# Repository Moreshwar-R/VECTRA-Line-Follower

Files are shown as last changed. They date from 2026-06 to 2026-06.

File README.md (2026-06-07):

# 🏁 VECTRA — Line Follower Robot

**ESP32 · TB6612FNG · 10-channel IR array · LSRB intersection logic + Anti-Wobble PID**

VECTRA is a high-speed competition line follower designed to stay locked on the track even when the layout changes from one event to the next. A wide 10-channel IR array reads sharp turns, acute angles and intersections, while decisive LSRB logic layered over a tuned PID controller keeps every junction predictable. Built around an ESP32 and a TB6612FNG driver, it balances speed, stability and fast trackside tuning.

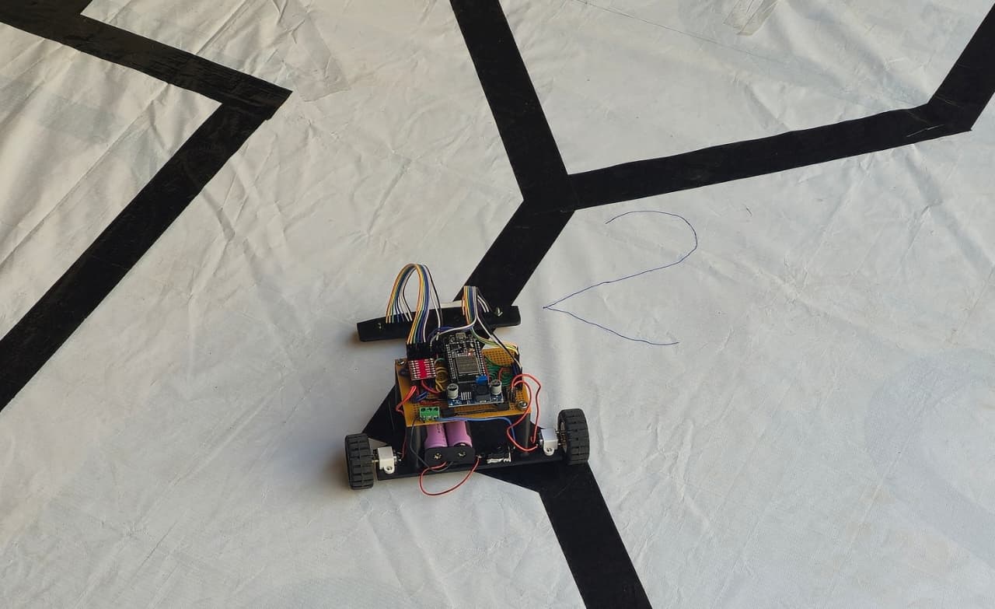
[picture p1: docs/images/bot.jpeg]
VECTRA line follower robot


<br>

VECTRA run demo

</div>

---

## ✨ Features

- **Wide 10-sensor coverage** — handles different track layouts without re-wiring.
- **LSRB intersection logic** — Left > Straight > Right priority at junctions.
- **Anti-wobble PID** — dead-band stops shivering on straights, saving time.
- **Line-lost recovery** — remembers last turn direction and sweeps back to the line.
- **Efficient drive** — TB6612FNG H-bridge with N20 micro-gear motors.

---

## 🧩 Components

| Component | Qty | Description |
|---|:---:|---|
| ESP32 DevKit (30-pin) | 1 | Dual-core microcontroller — reads the sensors and runs the control loop. |
| TB6612FNG motor driver | 1 | Dual H-bridge that drives both motors efficiently and cool. |
| N20 6V micro-gear motor + wheel | 2 | Provides drive; compact and quick. |
| Front caster wheel | 1 | Third contact point for smooth balance. |
| 10-channel reflective IR array | 1 | Senses the line; wide span covers changing track maps. |
| LM2596 buck module | 1 | Steps the 7.4 V battery down to a clean 5 V for the logic. |
| 2S Li-ion battery (7.4 V) | 1 | Main power source. |
| SPST switch | 1 | Master power cut-off. |
| Chassis, standoffs, wires, connectors | — | Frame and interconnections. |

---

## ⚙️ How It Works

1. **Read** the IR array and compute a weighted line `error` (outer sensors pull harder).
2. **Intersections / acute turns (LSRB):** left has priority, straight beats right, sharp turns snap.
3. **Line lost:** spin toward the last known turn until the line is reacquired.
4. **PID steering:** `correction = Kp·error + Kd·(error − lastError)`, applied differentially.

---

## 🛠️ Hardware Design

**Schematic**

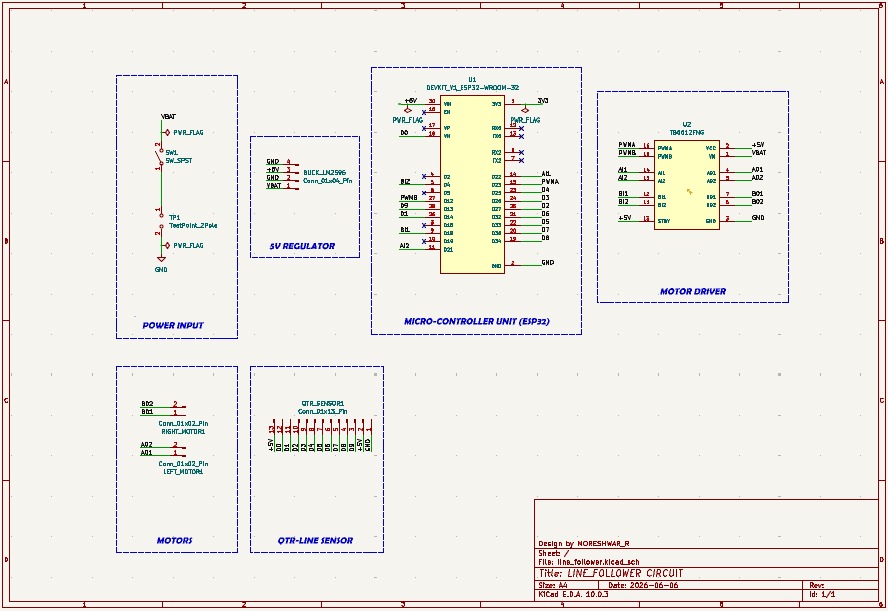
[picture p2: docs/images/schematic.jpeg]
Schematic


<br>

**PCB Layout**

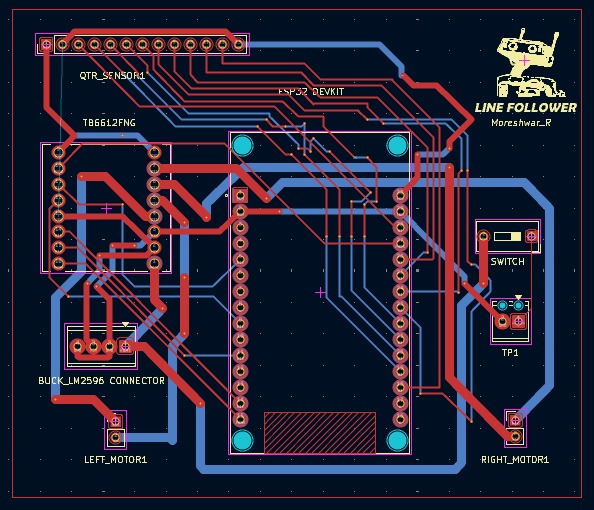
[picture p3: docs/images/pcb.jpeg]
PCB layout


<br>

**3D Model**

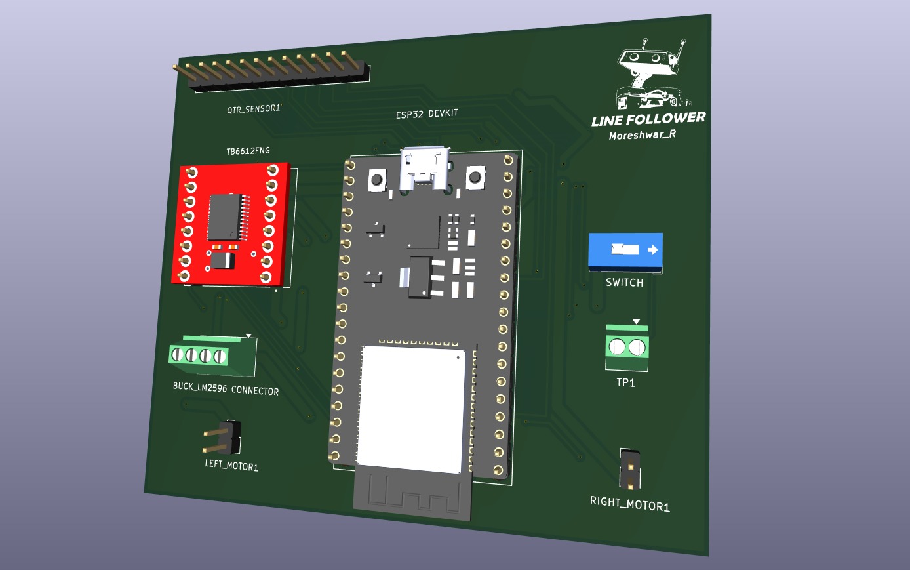
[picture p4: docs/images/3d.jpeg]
3D model


</div>

---

## 💾 Firmware & Tuning

- Sketch → [`firmware/line_follower.ino`](firmware/line_follower.ino)
- Board: **ESP32 Dev Module** · Library: **QTRSensors**

| Variable | Default | Role |
|---|:---:|---|
| `Kp` | 15 | Correction strength |
| `Kd` | 30000 | Damping / overshoot control |
| `baseSpeed` | 250 | Cruise speed (0–255) |
| `THRESHOLD` | 4090 | Black/white cutoff (recalibrate per track) |

---

## 📜 License

- Released under the **MIT License** — see [`LICENSE`](LICENSE).
- Free to use, fork and race.

---

## 🏷️ Topics

`#LineFollower` `#ESP32` `#TB6612FNG` `#PID` `#LSRB` `#Robotics` `#Arduino` `#Embedded` `#KiCad`

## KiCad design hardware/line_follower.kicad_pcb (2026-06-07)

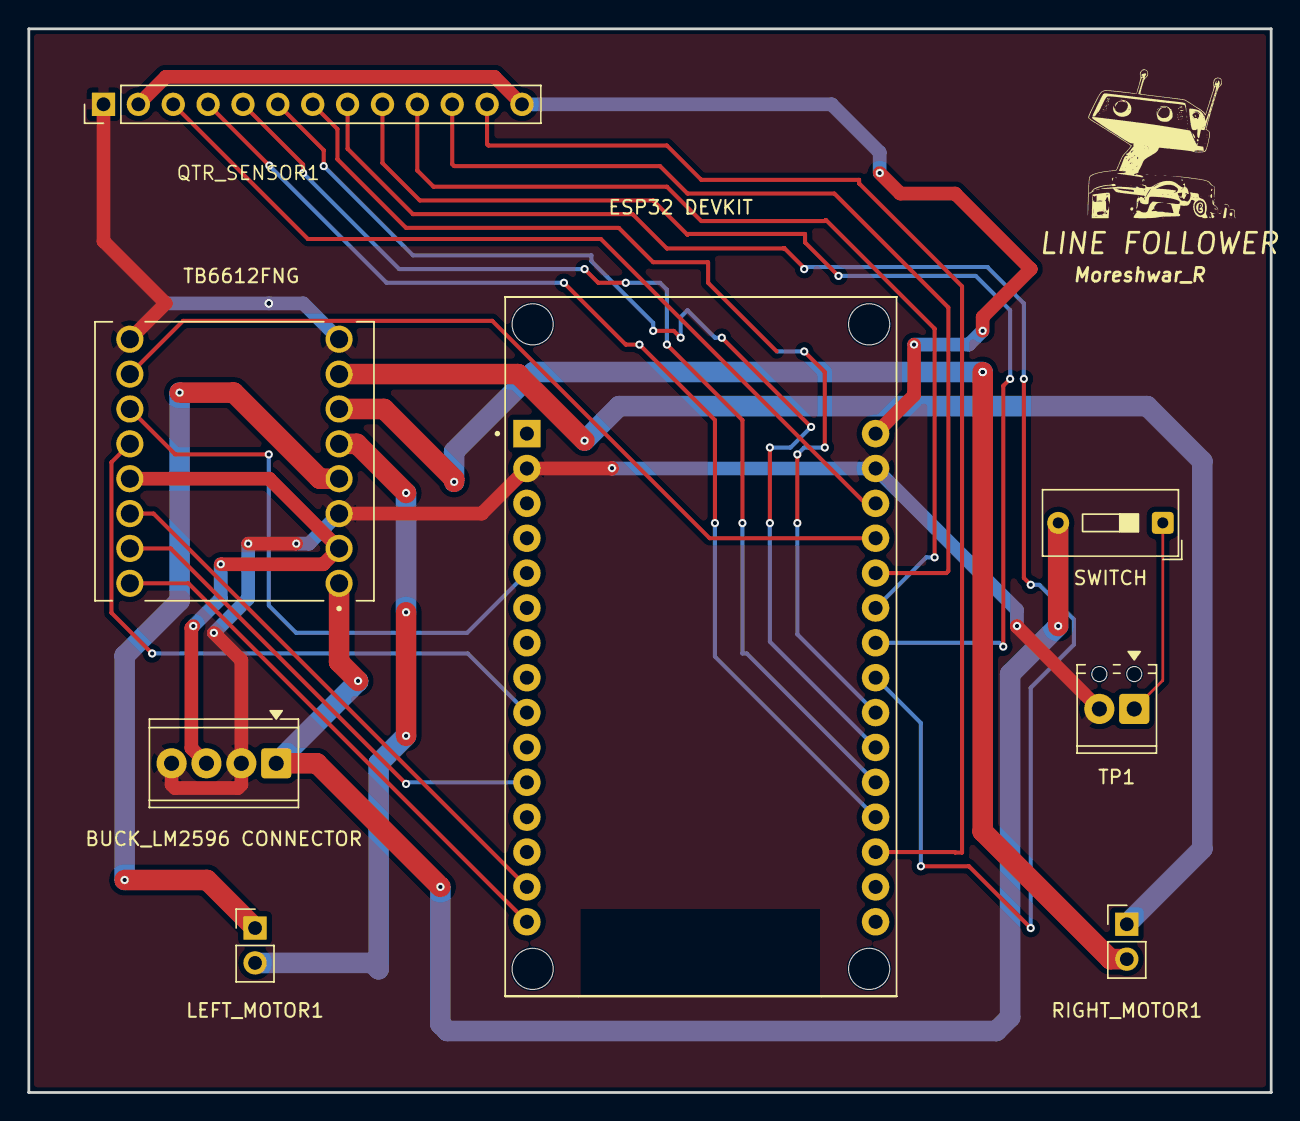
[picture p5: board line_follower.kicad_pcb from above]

Board: 2 copper layers, 90.5 x 77.5 mm, 8 parts (0 on the bottom side), 24 nets.

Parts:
BUCK_LM2596 CONNECTOR: Conn_01x04_Pin; TerminalBlock_Phoenix_MPT-0,5-4-2.54_1x04_P2.54mm_Horizontal
ESP32 DEVKIT: DEVKIT_V1_ESP32-WROOM-32; MODULE_DEVKIT_V1_ESP32-WROOM-32
LEFT_MOTOR1: Conn_01x02_Pin; PinHeader_1x02_P2.54mm_Vertical
QTR_SENSOR1: Conn_01x13_Pin; PinHeader_1x13_P2.54mm_Vertical
RIGHT_MOTOR1: Conn_01x02_Pin; PinHeader_1x02_P2.54mm_Vertical
SWITCH: SW_SPST; SW_DIP_SPSTx01_Slide_9.78x4.72mm_W7.62mm_P2.54mm
TB6612FNG: TB6612FNG; MODULE_ROB-14450
TP1: TestPoint_2Pole; TerminalBlock_Phoenix_MPT-0,5-2-2.54_1x02_P2.54mm_Horizontal

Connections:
/+5V: BUCK_LM2596 CONNECTOR.3, ESP32 DEVKIT.30 (VIN), QTR_SENSOR1.2, QTR_SENSOR1.13, TB6612FNG.2 (VCC), TB6612FNG.13 (STBY)
/A01: LEFT_MOTOR1.1, TB6612FNG.4 (A01)
/A02: LEFT_MOTOR1.2, TB6612FNG.5 (A02)
/AI1: ESP32 DEVKIT.14 (D22), TB6612FNG.14 (AI1)
/AI2: ESP32 DEVKIT.11 (D21), TB6612FNG.15 (AI2)
/B01: RIGHT_MOTOR1.1, TB6612FNG.7 (B01)
/B02: RIGHT_MOTOR1.2, TB6612FNG.6 (B02)
/BI1: ESP32 DEVKIT.9 (D18), TB6612FNG.12 (BI1)
/BI2: ESP32 DEVKIT.5 (D4), TB6612FNG.11 (BI2)
/D0: ESP32 DEVKIT.18 (VN), QTR_SENSOR1.12
/D1: ESP32 DEVKIT.26 (D14), QTR_SENSOR1.11
/D2: ESP32 DEVKIT.25 (D27), QTR_SENSOR1.10
/D3: ESP32 DEVKIT.24 (D26), QTR_SENSOR1.9
/D4: ESP32 DEVKIT.23 (D25), QTR_SENSOR1.8
/D5: ESP32 DEVKIT.22 (D33), QTR_SENSOR1.7
/D6: ESP32 DEVKIT.21 (D32), QTR_SENSOR1.6
/D7: ESP32 DEVKIT.20 (D35), QTR_SENSOR1.5
/D8: ESP32 DEVKIT.19 (D34), QTR_SENSOR1.4
/D9: ESP32 DEVKIT.28 (D13), QTR_SENSOR1.3
/PWMA: ESP32 DEVKIT.15 (D23), TB6612FNG.16 (PWMA)
/PWMB: ESP32 DEVKIT.27 (D12), TB6612FNG.10 (PWMB)
/VBAT: BUCK_LM2596 CONNECTOR.1, SWITCH.2 (B), TB6612FNG.1 (VM)
GND: BUCK_LM2596 CONNECTOR.2, BUCK_LM2596 CONNECTOR.4, ESP32 DEVKIT.2 (GND), ESP32 DEVKIT.29 (GND), QTR_SENSOR1.1, TB6612FNG.3 (GND), TB6612FNG.8 (GND), TB6612FNG.9 (GND), TP1.2
unnamed: SWITCH.1 (A), TP1.1

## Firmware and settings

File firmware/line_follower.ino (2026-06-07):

/*
 * VECTRA - High-Speed Line Follower
 * ESP32 + TB6612FNG + 8-array IR + 2 wing sensors
 * Logic: Decisive LSRB intersections + line-lost recovery + anti-wobble PID

#include <Arduino.h>
#include <QTRSensors.h>

// ==========================================================
// 1. HARDWARE SETUP
// ==========================================================
QTRSensors qtr;

// Motor Pins (Channel A = LEFT, Channel B = RIGHT)
#define PWMA 23
#define AIN1 21
#define AIN2 22
#define PWMB 16
#define BIN1 18
#define BIN2 4

// Main 8-array sensor pins (analog)
const uint8_t SensorCount = 8;
const uint8_t sensorPins[SensorCount] = {14, 27, 26, 25, 33, 32, 35, 34};
uint16_t sensorValues[SensorCount];

// Wing sensors (analog)
#define PIN_LEFT_WING  39   // GPIO39 / VN pad
#define PIN_RIGHT_WING 13

// Black/white threshold (12-bit ADC, 0..4095)
const uint16_t THRESHOLD = 4090;

// ==========================================================
// 2. TUNABLE VARIABLES
// ==========================================================
float Kp = 15;
float Kd = 30000;
int   baseSpeed = 250;
int   rightMotorOffset = 10;
float lastError = 0;

// Logic memory: -1 = last turned Left, 1 = last turned Right
int lastTurn = 0;

// ==========================================================
// 3. HELPER FUNCTIONS
// ==========================================================
void driveMotors(int left, int right) {
  if (right > 0)      right += rightMotorOffset;
  else if (right < 0) right -= rightMotorOffset;

  left  = constrain(left,  -255, 255);
  right = constrain(right, -255, 255);

  if (left >= 0) { digitalWrite(AIN1, HIGH); digitalWrite(AIN2, LOW); }
  else           { digitalWrite(AIN1, LOW);  digitalWrite(AIN2, HIGH); left = -left; }

  if (right >= 0) { digitalWrite(BIN1, HIGH); digitalWrite(BIN2, LOW); }
  else            { digitalWrite(BIN1, LOW);  digitalWrite(BIN2, HIGH); right = -right; }

  analogWrite(PWMA, left);
  analogWrite(PWMB, right);
}

// Weighted-average error from the main 8 sensors
float calculateError() {
  float weightedSum = 0;
  int   activeSensors = 0;
  int   weights[8] = {-40, -30, -20, -10, 10, 20, 30, 40};

  for (int i = 0; i < 8; i++) {
    if (sensorValues[i] > THRESHOLD) {
      weightedSum += weights[i];
      activeSensors++;
    }
  }
  if (activeSensors == 0) return -999;   // line lost
  return weightedSum / activeSensors;
}

void setup() {
  Serial.begin(115200);

  pinMode(AIN1, OUTPUT); pinMode(AIN2, OUTPUT); pinMode(PWMA, OUTPUT);
  pinMode(BIN1, OUTPUT); pinMode(BIN2, OUTPUT); pinMode(PWMB, OUTPUT);

  pinMode(PIN_LEFT_WING,  INPUT);
  pinMode(PIN_RIGHT_WING, INPUT);

  qtr.setTypeAnalog();
  qtr.setSensorPins(sensorPins, SensorCount);

  delay(500);
}

// ==========================================================
// 4. MAIN LOOP (decisive logic + PID)
// ==========================================================
void loop() {
  // 1. Read sensors
  qtr.read(sensorValues);
  bool leftWing  = (analogRead(PIN_LEFT_WING)  > THRESHOLD);
  bool rightWing = (analogRead(PIN_RIGHT_WING) > THRESHOLD);
  bool centerBlack = (sensorValues[3] > THRESHOLD) || (sensorValues[4] > THRESHOLD);

  // 2. Error
  float error = calculateError();

  // ---- PRIORITY 1: LSRB intersection + acute logic ----
  // CASE A: acute left (V-shape)
  if (leftWing && !centerBlack) {
    lastTurn = -1;
    driveMotors(-120, 160);
    delay(50);
    return;
  }
  // CASE B: normal left (left priority)
  else if (leftWing && centerBlack) {
    lastTurn = -1;
    driveMotors(-120, 160);
    delay(50);
    return;
  }
  // CASE C: straight beats right -> fall through to PID
  else if (centerBlack && (rightWing || sensorValues[6] > THRESHOLD || sensorValues[7] > THRESHOLD)) {
    // do nothing; go straight via PID
  }
  // CASE D: acute right (V-shape)
  else if (!centerBlack && (rightWing || sensorValues[6] > THRESHOLD || sensorValues[7] > THRESHOLD)) {
    lastTurn = 1;
    delay(50);
    driveMotors(160, -120);
    return;
  }

  // ---- PRIORITY 2: line lost recovery ----
  if (error == -999) {
    if (lastTurn == 1) driveMotors(150, -150);
    else               driveMotors(-150, 150);
    return;
  }

  // ---- PRIORITY 3: anti-wobble PID ----
  if (abs(error) < 4) error = 0;            // dead-band

  float P = error * Kp;
  float D = (error - lastError) * Kd;
  float correction = P + D;
  lastError = error;

  int leftSpeed  = baseSpeed + correction;
  int rightSpeed = baseSpeed - correction;
  driveMotors(leftSpeed, rightSpeed);

  if (error < -10)      lastTurn = 1;
  else if (error > 10)  lastTurn = -1;
}
